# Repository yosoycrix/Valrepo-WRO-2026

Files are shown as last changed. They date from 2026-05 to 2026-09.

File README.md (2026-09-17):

# Equipo [Team ValGrind]: WRO 2026

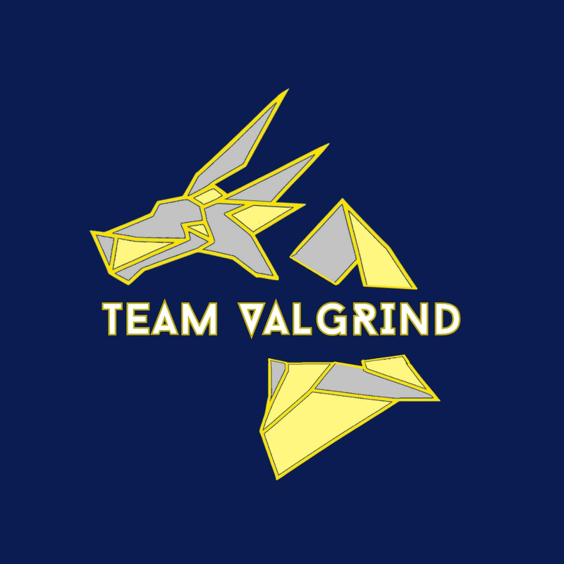
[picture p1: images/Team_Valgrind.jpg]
Team Photo


---

# Índice

- [1. Nuestro Equipo](#1-nuestro-equipo)
  - [1.1 Integrantes](#11-integrantes)
  - [1.2 Origenes](#12-origenes)
  - [1.3 Nuestro Objetivo](#13-nuestro-objetivo)
- [2. El Robot](#2-el-robot)
  - [2.1 Videos del Robot](#21-videos-del-robot)
  - [2.2 Apartado Mecanico](#22-apartado-mecanico)
  - [2.3 Impresion 3D](#23-Impresion-3d)
    - [2.3.1 Justificacion de Diseño](#231-justificación-de-diseño)
  - [2.4 Movilidad](#24-movilidad)
  - [2.5 Sistema de Movimiento y Traccion](#25-sistema-de-movimiento-y-traccion)
  - [2.6 Piezas de Mecanica](#26-piezas-de-mecanica)
    - [2.6.1 Diferencial y Eje de transmision](#261-diferencial-y-eje-de-transmisión-impreso-en-3d)
    - [2.6.2 Servomotor](#262-servomotor-injora-180)
    - [2.6.3 Motor](#263-motor-hytech-ga37-520)
    - [2.6.4 Tornillos, Tuercas y Arandelas](#264-tornillos-tuercas-de-seguridad-y-arandelas-m2-y-m3)
- [3. Apartado Electronico](#3-apartado-electronico)
  - [3.1 Piezas de Electronica](#31-piezas-de-electronica)
    - [3.1.1 Baterias](#311-baterias)
    - [3.1.2 Step Down](#312-step-down)
    - [3.1.3 Motor Driver](#313-motor-driver)
    - [3.1.4 Ultrasonico](#314-sensor-de-ultrasonido)
    - [3.1.5 Giroscopio](#315-giroscopio)
    - [3.1.6 Huskylens](#316-huskylens-2)
  - [3.2 Microcontrolador](#32-microcontrolador)
    - [3.2.2 ESP32](#322-esp32-wroom-32)
  - [3.3 Diagrama de Conexiones](#33-diagrama-de-conexiones)
    - [3.3.1 Distribucion de Pines](#331-distribucion-de-pines)
    - [3.3.2 Estrategia de Corriente](#332-estrategia-de-corriente)
    - [3.3.3 Sistema de Alimetacion](#333-sistema-de-alimentacion)
- [4. Apartado de Programacion](#4-apartado-de-programacion)
  - [4.1 Desafio Abierto](#41-desafio-abierto)
    - [4.1.1 Flowchart Abierta](#411-flowchart-abierta)
    - [4.1.2 Explicación del Codigo](#412-explicacion-del-codigo)
    - [4.1.3 Pruebas en Pista](#413-pruebas-en-pista)
  - [4.2 Desafio Cerrado](#42-desafio-cerrado)
    - [4.2.1 Flowchart Cerrada](#421-flowchart-cerrada)
    - [4.2.2 Explicación del Codigo](#422-explicacion-del-codigo)
    - [4.2.3 Pruebas de Esquivamiento](#423-pruebas-de-esquivamiento)
- [5. Pensamiento Sistemico y Decisiones de Ingeneria](#5-pensamiento-sistemico-y-decisiones-de-ingeneria)
  - [5.1 Enfoque de Pensamiento Sistemico](#51-enfoque-de-pensamiento-sistémico)
  - [5.2 Trade Offs e Iteraciones de Ingeneria](#52-trade-offs-e-iteraciones-de-ingeniería)
  - [5.3 Validacion Robutez e Itegracion Tecnica](#53-validación-robustez-e-integración-técnica)
  - [5.4 Diario de Ingeneria Bitacora de Componentes e Iteraciones](#54-diario-de-ingeniería-bitácora-de-componentes-e-iteraciones)
- [6. Randomizador](#6-Randomizador)
- [7. Recursos para armar nuestro robot](#7-recursos-para-hacer-el-robot)

---

## Estructura del Repositorio
- [T-photos/](https://github.com/yosoycrix/Valrepo-WRO-2026/tree/main/t-photos) - Fotos del Team
- [V-photos/](https://github.com/yosoycrix/Valrepo-WRO-2026/tree/main/v-photos) - Fotos del Robot
- [Schemes/](https://github.com/yosoycrix/Valrepo-WRO-2026/tree/main/schemes) - Eschematic diagrams
- [Src/](https://github.com/yosoycrix/Valrepo-WRO-2026/tree/main/src) - Codigo
- [Models/](https://github.com/yosoycrix/Valrepo-WRO-2026/tree/main/models) - Diseños 3D
- [Others/](https://github.com/yosoycrix/Valrepo-WRO-2026/tree/main/others) - Otros archivos
- [Videos/](https://github.com/yosoycrix/Valrepo-WRO-2026/tree/main/videos) - Videos
- [Images/](https://github.com/yosoycrix/Valrepo-WRO-2026/tree/main/images) - Imagenes
      
---

## 1. Nuestro Equipo

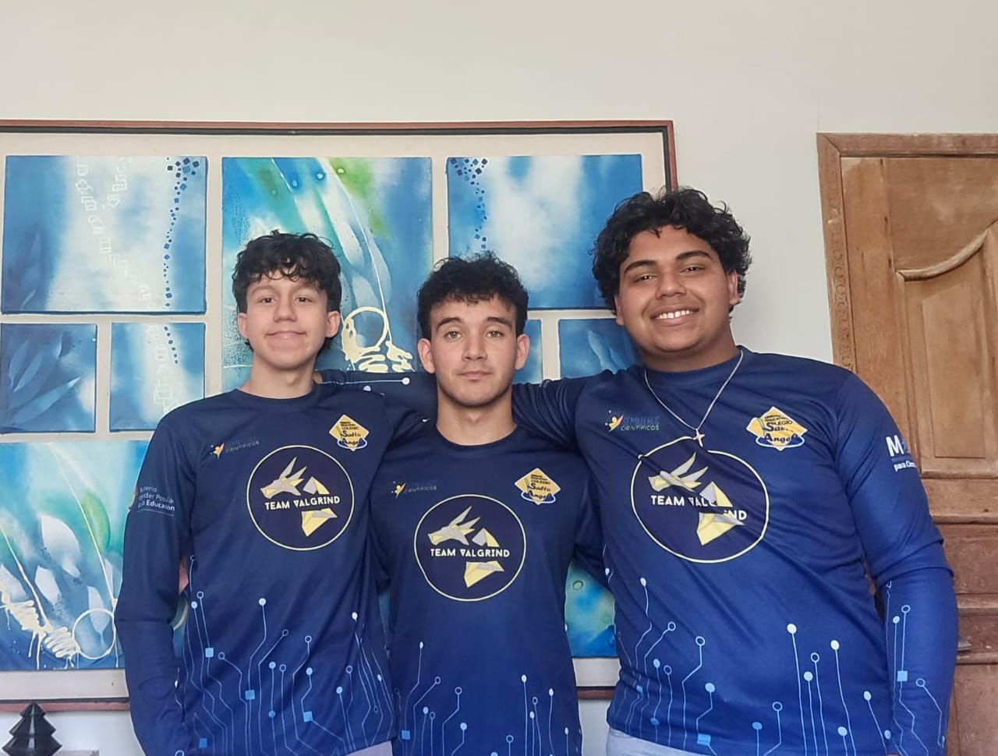
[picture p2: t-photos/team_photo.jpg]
Team Photo


Somos **[Team ValGrind]**, entusiastas de la robótica y la innovación. Representamos a nuestra institución en las fases Regionales de la **WRO 2026**.

---

### 1.1 Integrantes

<table>
  <tr>
    <!-- Foto de Perfil -->
    <td width="280px" align="center" style="border: none;">
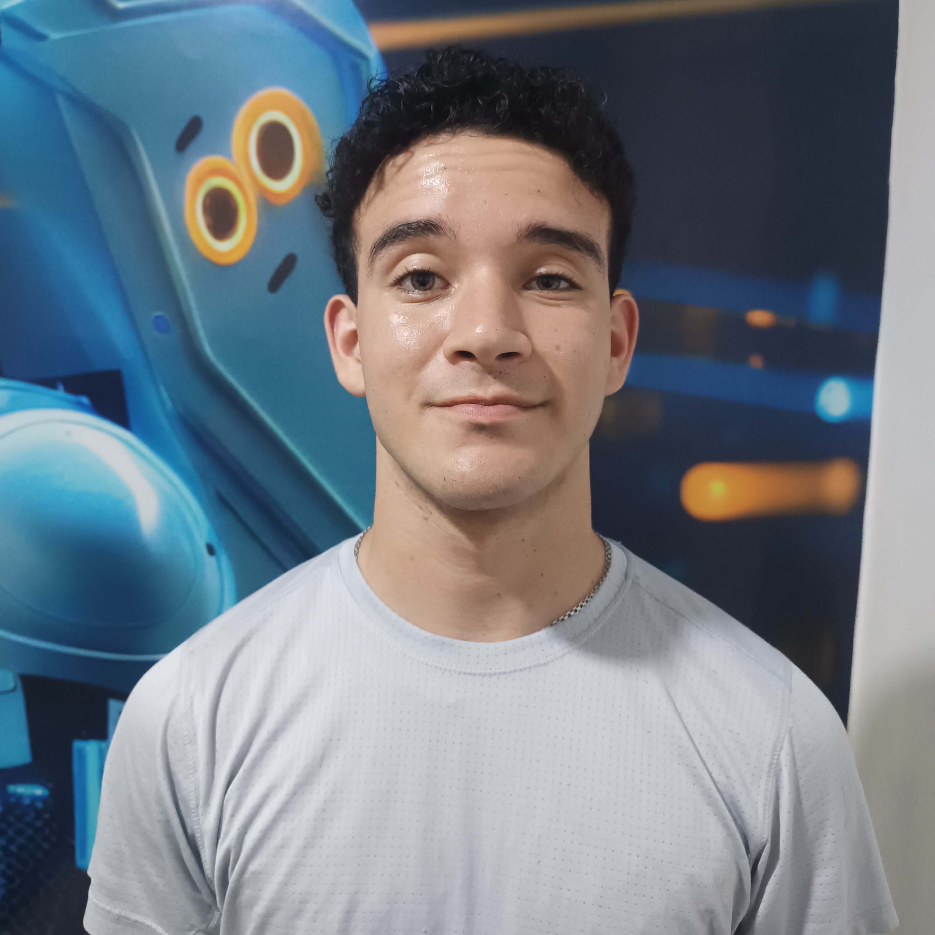
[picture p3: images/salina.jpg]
      
    </td>
    <!-- Información del Integrante -->
    <td style="border: none; padding-left: 20px; vertical-align: top;">
      <h2>Sebastián Salina</h2>
      <p><b>🎂 Edad:</b> 18 años (22/08/2008)</p>
      <p><b>🎖️ Rol:</b> Capitán / Mecánico del equipo</p>
      <hr>
      <p><b>🛠️ Habilidades:</b></p>
      <ul>
        <li>Estudiante de ing Mecatronica.</li>
        <li>Diseño de piezas en 3D (CAD).</li>
        <li>Tecnico en impresión 3D.</li>
        <li>Mantenimiento y ensamblaje mecánico.</li>
      </ul>
      <p><b>✨ Fun Fact:</b> <i>Una vez imprimió un Pokémon gigante de filamento para Cristóbal.</i></p>
    </td>
  </tr>
</table>

<table>
  <tr>
    <!-- Foto de Perfil -->
    <td width="280px" align="center" style="border: none;">
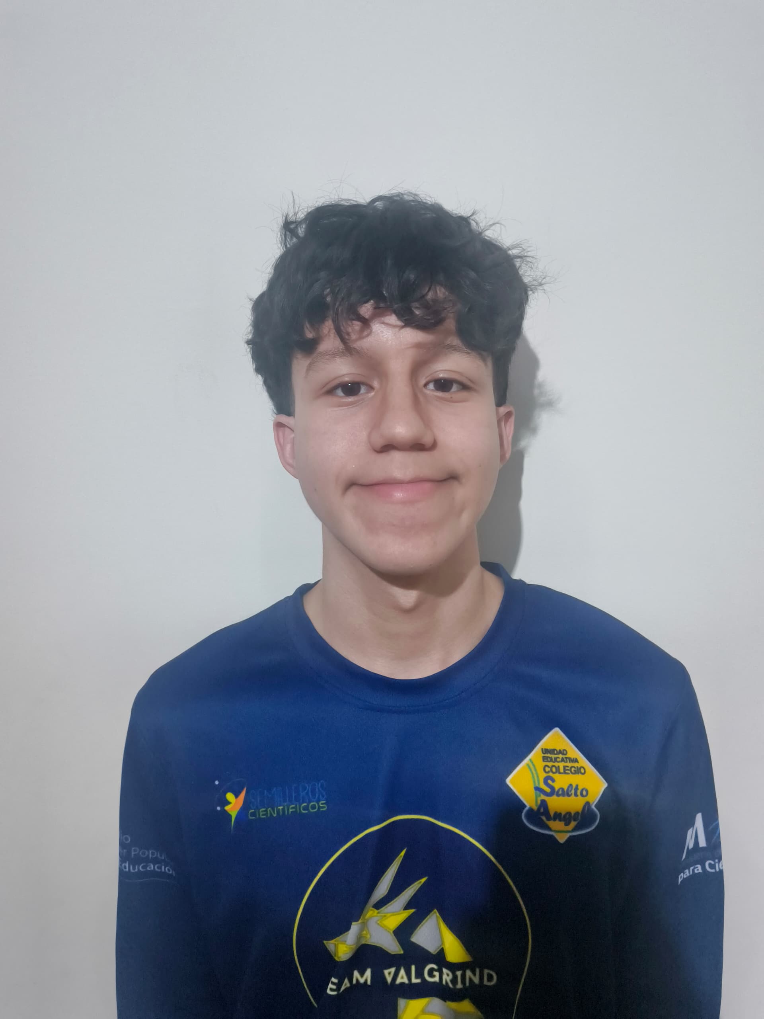
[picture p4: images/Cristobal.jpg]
      
    </td>
    <!-- Información del Integrante -->
    <td style="border: none; padding-left: 20px; vertical-align: top;">
      <h2>Cristobal Mogollón</h2>
      <p><b>🎂 Edad:</b> 16 años (14/07/2010)</p>
      <p><b>🎖️ Rol:</b> Programador / Documentador</p>
      <hr>
      <p><b>💻 Habilidades:</b></p>
      <ul>
        <li>Programación en C++ y Arduino IDE.</li>
        <li>Manejo de la electrónica y sensores.</li>
        <li>Dominio con Git y GitHub.</li>
      </ul>
      <p><b>✨ Fun Fact:</b> <i>Una vez le pidió a Sebastián imprimir un Pokémon gigante de filamento.</i></p>
    </td>
  </tr>
</table>

<table>
  <tr>
    <!-- Foto de Perfil -->
    <td width="280px" align="center" style="border: none;">
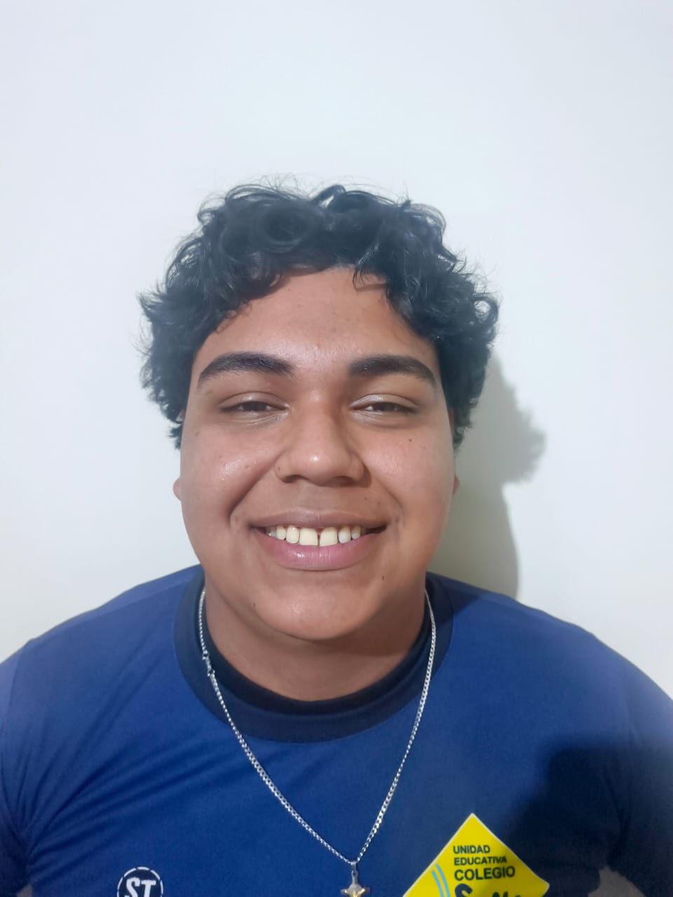
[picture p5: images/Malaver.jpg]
      
    </td>
    <!-- Información del Integrante -->
    <td style="border: none; padding-left: 20px; vertical-align: top;">
      <h2>Diego Malaver</h2>
      <p><b>🎂 Edad:</b> 16 años (09/09/2010)</p>
      <p><b>🎖️ Rol:</b> Mecanico / Electronico</p>
      <hr>
      <p><b>⚙️ Habilidades:</b></p>
      <ul>
        <li>Manejo de la Mecanica.</li>
        <li>Manejo de la electrónica.</li>
        <li>Dominio con Github.</li>
      </ul>
      <p><b>✨ Fun Fact:</b> <i>Le prestaron la camisa de Cristobal del equipo y le quedo apretada.</i></p>
    </td>
  </tr>
</table>

- **Institución:** [Colegio Salto Ángel](https://www.instagram.com/colegiosaltoangel)
- **Instagram Oficial:** [@team_valgrind](https://instagram.com/team_valgrind)
- **Contáctanos:** [valgrind2026@gmail.com](mailto:valgrind2026@gmail.com)
- **Youtube:**
[Team ValGrind](https://youtube.com/@teamvalgrind?si=ZJbz7CX9eOX75H2U)

---

### 1.2 Origenes

El nombre de nuestro equipo fue decidido por los tres integrantes a partir de un clásico compilador de C++ llamado de la misma forma, el cual es representado por un logotipo de un dragón hecho con origami. El nombre "ValGrind" también hace referencia a la mitología nórdica debido a las legendarias Valquirias que habitan en este.

 (https://postimg.cc/gryddns4)

> ### ¿Por qué nuestro robot se llama Heimdall?

Este nombre no solo es un guiño a la mitología mencionada, sino que además corresponde al dios conocido como el guardián de las puertas de Asgard y del puente Bifröst, que conecta los Nueve Mundos. Al ser un personaje imponente, consideramos que es un nombre apropiado para representar a nuestro robot en la WRO.

---  

### 1.3 Nuestro Objetivo

(https://postimg.cc/t1LyR68v)

#### "Diseñar, Construir y Programar"
 Un robot autónomo capaz de superar los desafíos de la WRO 2026, utilizando innovación y trabajo en equipo para lograr un desempeño sobresaliente en la etapa regional y avanzar a la nacional. Para llegar a esto, hemos pasado los últimos meses diseñando, construyendo, armando y programando nuestro más nuevo proyecto "Heimdall"

> [!NOTE]
> La World Robot Olympiad (WRO) es una competencia internacional de robótica educativa que se desarrolla en varias fases, y nuestro equipo lógicamente tiene que comenzar por la fase regional, mediante la cual al ganarla se accede a la Fase Nacional. Cada país organiza su propio torneo clasificatorio, donde equipos de jóvenes compiten en distintas categorías, aplicando conocimientos de robótica y STEAM. Por último, la fase a la cual nuestro equipo quiere llegar es la Final Internacional. Los equipos ganadores de cada país participan en la competencia global, donde enfrentan desafíos más complejos y compiten con representantes de más de 95 países 

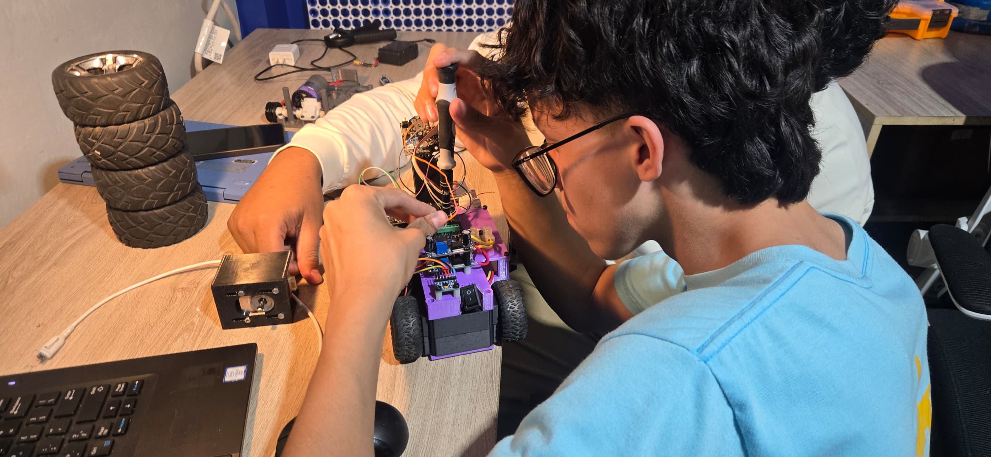
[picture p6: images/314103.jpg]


Aún así, nuestro único objetivo no es solamente ganar, como un equipo unido también tenemos la convicción de poder crear un robot no solo funcional, sino que llene nuestras expectativas; A pesar de ser intangible nuestro deseo de poder culminar nuestro proyecto como un equipo unido y verlo brillar, también es una meta importante para nosotros.

<p align="right">
  <a href="#inicio">Volver Al Inicio</a>
</p>

---

## 2. El Robot

<table>
  <tr>
    <td align="center">
      <b>Frontal</b><br>
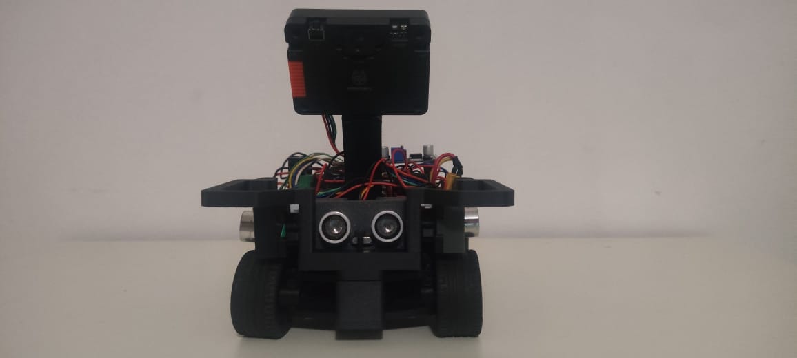
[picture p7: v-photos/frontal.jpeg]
      
    </td>
    <td align="center">
      <b>Posterior</b><br>
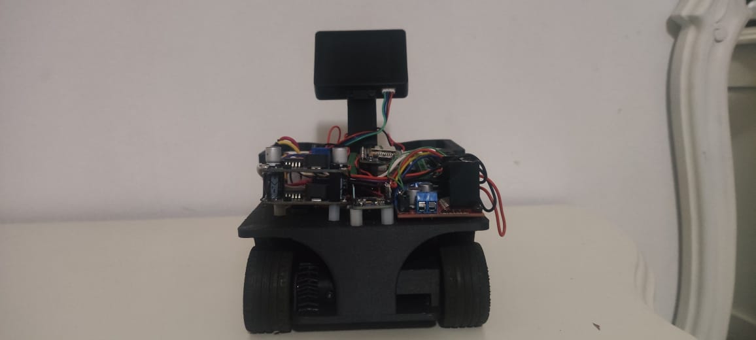
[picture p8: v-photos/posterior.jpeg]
      
    </td>
    <td align="center">
      <b>Lado Izquierdo</b><br>
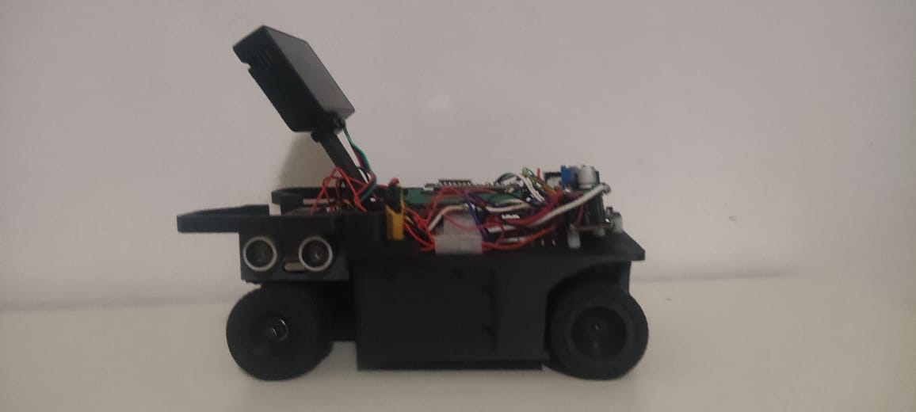
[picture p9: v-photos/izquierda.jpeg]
      
    </td>
  </tr>
  <tr>
    <td align="center">
      <b>Lado Derecho</b><br>
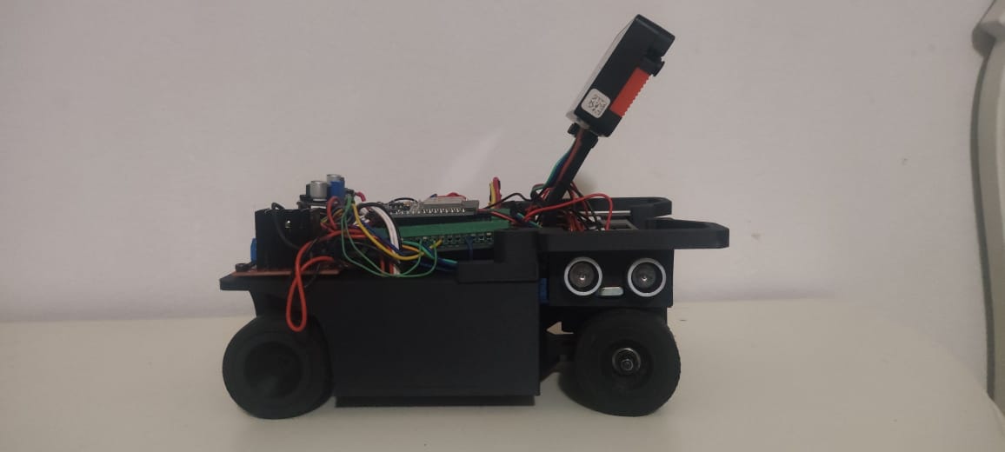
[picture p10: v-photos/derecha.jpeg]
      
    </td>
  <td align="center">
  <b>Superior</b><br>
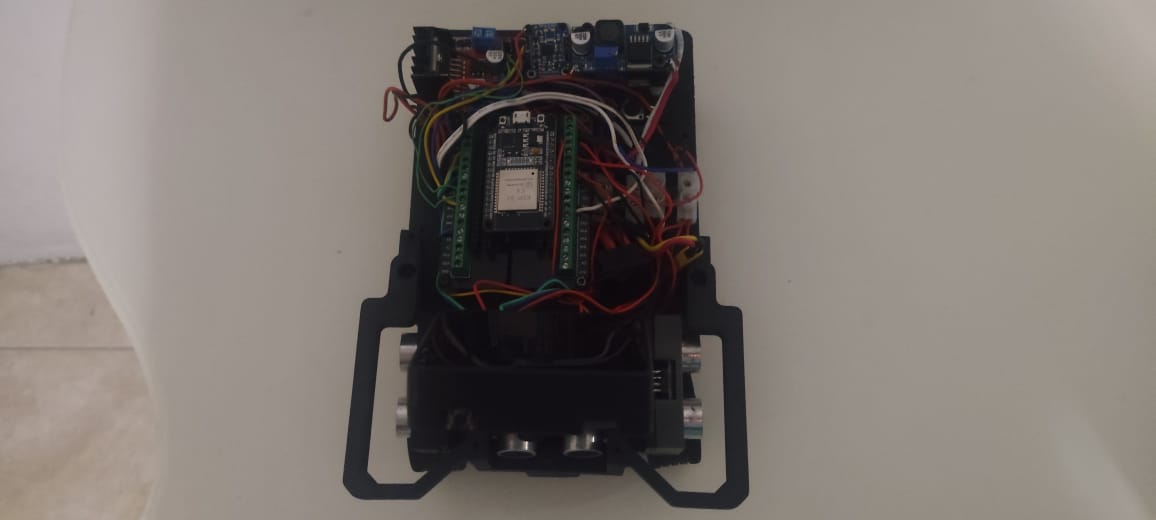
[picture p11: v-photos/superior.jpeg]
  
</td>
    <td align="center">
      <b>Inferior</b><br>
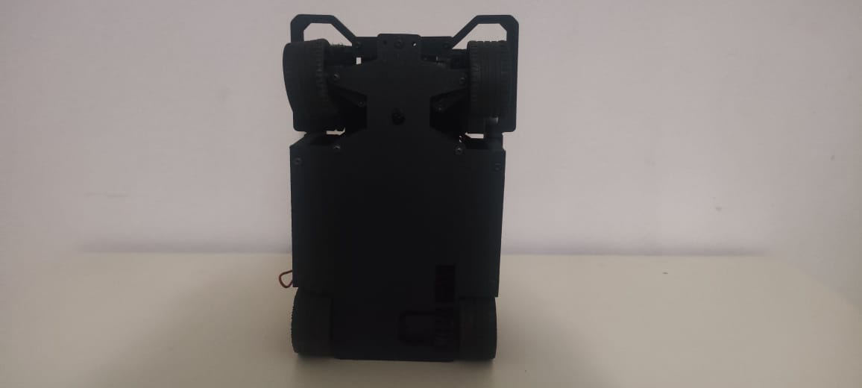
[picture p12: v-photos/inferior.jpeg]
      
    </td>
  </tr>
</table>

---

## 2.1 Videos Del Robot

<h3 align="left" style="font-size: 1.4em; font-weight: 800; color: #1f2328; margin-bottom: 12px; text-transform: uppercase; letter-spacing: 0.5px;"><strong>Open Challenge</strong></h3>

<section style="display: block; width: 100%;">
  <table align="left" style="border-collapse: collapse; border: none; margin-top: 0px; width: 100%;">
    <tr style="border: none;">
      <td align="center" style="padding: 10px; border: none; width: 50%; vertical-align: top;">
        <a href="https://www.youtube.com/watch?v=DzKUt2QOpJs" target="_blank" style="text-decoration: none; display: inline-block;">
          Open Challenge Video 3
          <br />
          <span style="color: #0366d6; font-size: 0.9em; font-weight: 500; display: inline-block; margin-top: 8px;">▶ Video Open Challenge #3</span>
        </a>
      </td>
      <td align="center" style="padding: 10px; border: none; width: 50%; vertical-align: top;">
        <a href="https://www.youtube.com/watch?v=JyEaFMhT2mY" target="_blank" style="text-decoration: none; display: inline-block;">
          Open Challenge Video 4
          <br />
          <span style="color: #0366d6; font-size: 0.9em; font-weight: 500; display: inline-block; margin-top: 8px;">▶ Video Open Challenge #4</span>
        </a>
      </td>
    </tr>
  </table>
</section>

<br clear="all" />

<h3 align="left" style="font-size: 1.4em; font-weight: 800; color: #1f2328; margin-bottom: 12px; text-transform: uppercase; letter-spacing: 0.5px;"><strong>Obstacle Challenge</strong></h3>

<section style="display: block; width: 100%;">
  <table align="left" style="border-collapse: collapse; border: none; margin-top: 0px; width: 50%;">
    <tr style="border: none;">
      <td align="center" style="padding: 10px; border: none; width: 100%; vertical-align: top;">
        <a href="https://www.youtube.com/watch?v=xPg1Bdj31Bs" target="_blank" style="text-decoration: none; display: inline-block;">
          Obstacle Challenge Video 1
          <br />
          <span style="color: #0366d6; font-size: 0.9em; font-weight: 500; display: inline-block; margin-top: 8px;">▶ Video Obstacle Challenge #1</span>
        </a>
      </td>
    </tr>
  </table>
</section>

<br clear="all" />

---

## 2.2 Apartado Mecanico

### 2.3 Impresion 3D

Antes de hablar de la movilidad o funcionalidad de nuestro robot, primero hay que explicar nuestros métodos de Diseño e Impresión 3D, los cuales se llevaron a cabo mediante Fusion 360

> [!NOTE]
> Fusion 360 es una plataforma de software de modelado 3D, CAD, CAM, CAE y PCB basada en la nube, destinada al diseño y la fabricación de productos. Nos permite diseñar y crear productos de acuerdo a sus especificaciones particulares, garantizando que cada pieza cumpla con los más exigentes criterios de estética, forma, ajuste y funcionalidad. Además, incorpora un conjunto integral de herramientas avanzadas para el diseño de placas de circuito impreso y componentes electrónicos, lo que facilita la conceptualización y materialización de cualquier idea, incluso las más complejas. Al implementar estas funciones, la plataforma optimiza significativamente tanto el tiempo como los costos asociados, asegurando que el proceso de producción se realice de manera eficiente y que las piezas obtenidas sean de la más alta calidad. Nosotros usamos esta herramienta gráfica y de diseño para realizar los diseños del chasis y las piezas personalizadas de nuestro robot.

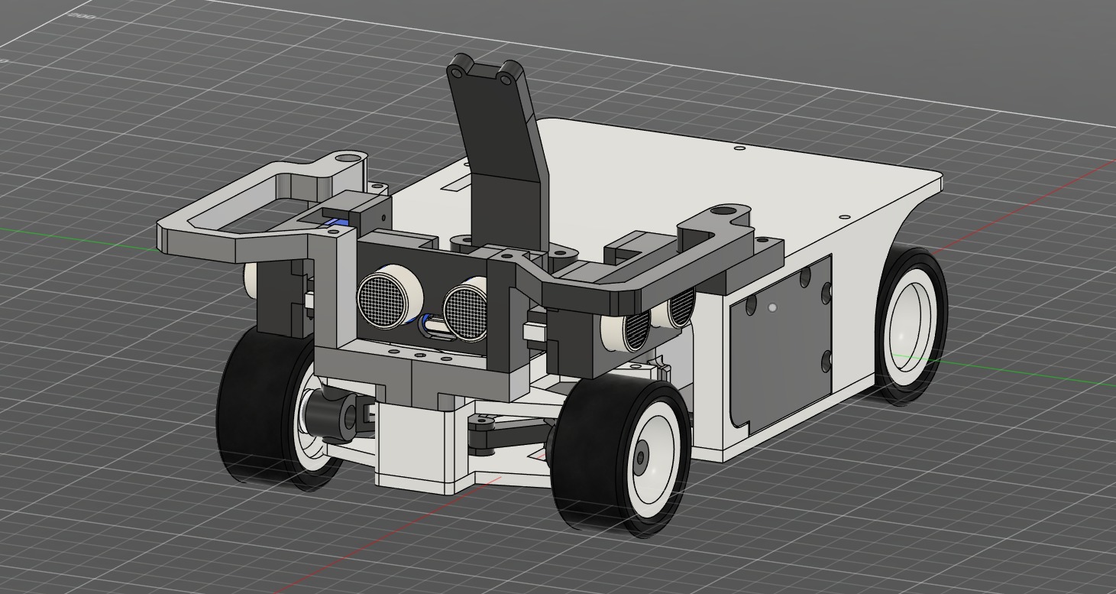
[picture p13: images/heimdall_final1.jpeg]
Hei=mdall3d


## 2.3.1 Justificación de Diseño

El desarrollo mecatrónico del prototipo se concibió bajo la filosofía de diseño **"compacto, funcional y robusto"**, buscando maximizar la eficiencia en pista, optimizar el uso del espacio interno y garantizar una respuesta dinámica precisa sin comprometer la rigidez estructural.

---

### Dimensionamiento y Distribución Espacial

El robot cuenta con una estructura de dimensiones reducidas de **19.6 cm de largo por 12.5 cm de ancho**, posicionándose como un chasis ultra compacto. Esta decisión de diseño persigue objetivos clave:
* **Centro de gravedad bajo y balanceado:** La disposición horizontal de los componentes internos distribuye la masa en un solo plano horizontal, minimizando la inercia rotacional y evitando volcamientos en maniobras a alta velocidad.
* **Maniobrabilidad en pista:** El empaquetamiento compacto permite abordar curvas cerradas con mayor radio de giro efectivo dentro del trazado.
* **Rigidez estructural:** La densidad del chasis y la calidad de construcción eliminan la flexión ante aceleraciones bruscas y cambios repentinos de dirección.

---

### Tren Delantero y Dirección Ackermann

A diferencia de los sistemas de dirección convencionales con múltiples eslabones flotantes, se implementó una variante de **geometría Ackermann positivo** conectada directamente a un servomotor central.

<p align="center">
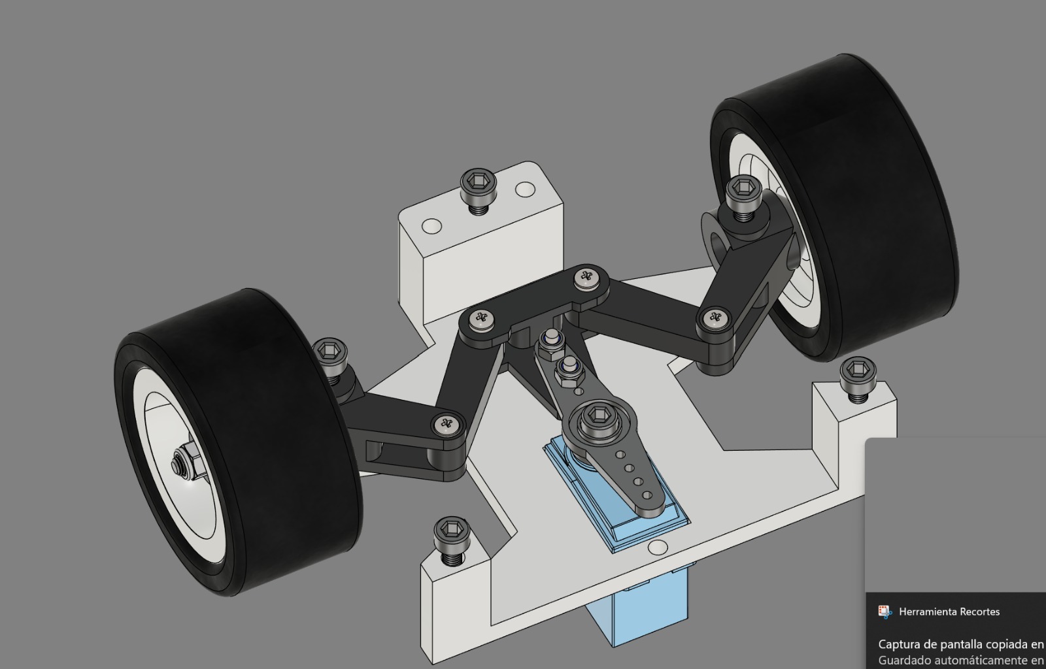
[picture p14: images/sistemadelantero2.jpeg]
Sistema de Dirección y Tren Delantero
  
</p>

* **Respuesta Inmediata y Cero Holguras:** Al acoplar el brazo del servomotor directamente al mecanismo de articulación de la dirección, se eliminan los puntos de juego mecánico. Esto garantiza un control de trayectoria inmediato y repetible.
* **Geometría Estable en un Solo Plano:** El mecanismo mantiene una geometría matemática pura que previene la alteración de los ángulos de giro ante fuerzas laterales generadas por el agarre en curvas.
* **Optimización de Torque y Energía:** Dado que el mecanismo ofrece una ventaja mecánica optimizada, el servomotor realiza un recorrido menor para lograr un ángulo de cruce agresivo, reduciendo la fricción, el desgaste mecánico y el consumo eléctrico pico.

---

### Rodadura y Acoplamiento a Medida

Para transmitir el torque al suelo de manera eficiente y mantener una baja distancia sensorial, se diseñó un sistema de rodadura a medida impreso en 3D.

<p align="center">
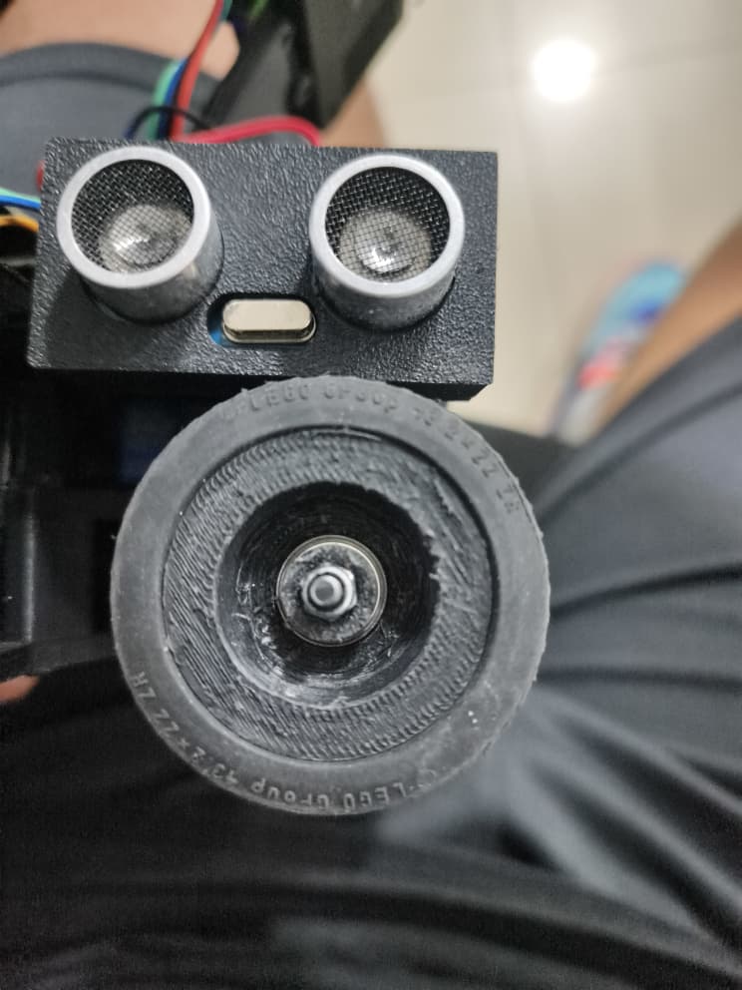
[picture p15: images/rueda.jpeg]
Detalle de Rueda y Rin Impreso en 3D
  
</p>

* **Rines Impresos en 3D con Alojamiento para Doble Rodamiento:** Los rines se diseñaron a medida con unas dimensiones de **43 mm de diámetro exterior por 22 mm de ancho**. Cada rin cuenta con una ranura interna a cada lado diseñada para alojar **dos rodamientos de bolas**, lo que elimina por completo el cabeceo de la rueda sobre el manguito/nudillo de dirección y garantiza una libertad de rotación fluida.
* **Tracción y Distancia Sensorial:** La geometría del conjunto rueda/rin asegura una superficie de contacto uniforme contra el vinil de la pista. Además, al mantener un perfil compacto de 43 mm, el chasis permanece lo suficientemente bajo como para ubicar los sensores ultrasónicos y la matriz de navegación a una distancia óptima del suelo.

---

### Transmisión y Diferencial Helicoidal Modificado

La etapa de tracción trasera resuelve uno de los principales retos de empaquetamiento mecánico mediante el rediseño integral de una caja diferencial compacta.

<p align="center">
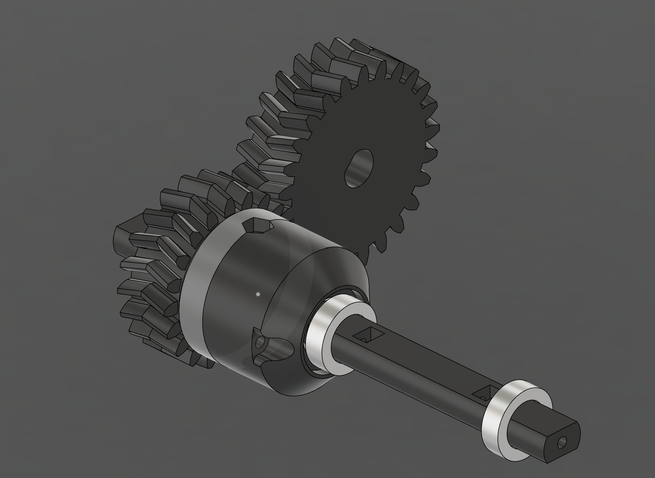
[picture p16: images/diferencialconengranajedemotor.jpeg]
Diseño CAD del Diferencial y Piñón Helicoidal
  
</p>

<p align="center">
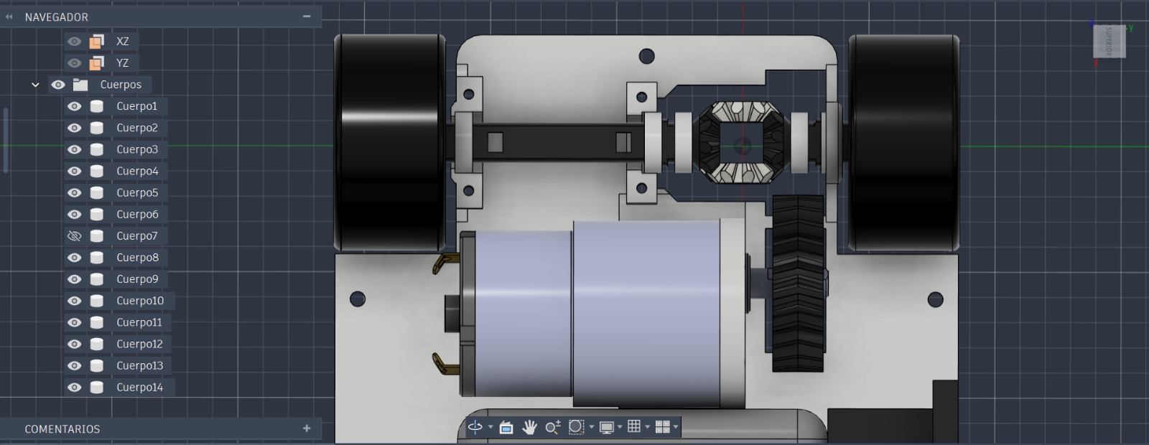
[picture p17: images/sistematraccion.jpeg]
Corte y Ensamblaje del Sistema de Tracción Trasera
  
</p>

* **Engranajes Helicoidales Dobles (Spur / Herringbone):** La corona externa del diferencial y el piñón de ataque del motor fueron rediseñados como engranajes helicoidales dobles. Este perfil cancela las fuerzas axiales y permite posicionar el motor de tracción de forma totalmente **horizontal y paralela al eje trasero**.
* **Reducción de Longitud (2 cm de ahorro):** La disposición horizontal del motor redujo la longitud total del chasis en **2 cm**, liberando el espacio central requerido para alojar la batería y el servo de dirección.
* **Cinemática Interna Eficiente:** Internamente, el diferencial conserva su configuración estándar de engranajes cónicos planetarios y satélites, asegurando una correcta distribución de torque entre las ruedas izquierdas y derechas al abordar curvas sin perder tracción ni forzar los motores.

---

### Integración Mecatrónica y Ensamblaje Final

El ensamblaje integral consolidado demuestra la convergencia de todos los subsistemas en una sola arquitectura monocasco y modular.

<p align="center">
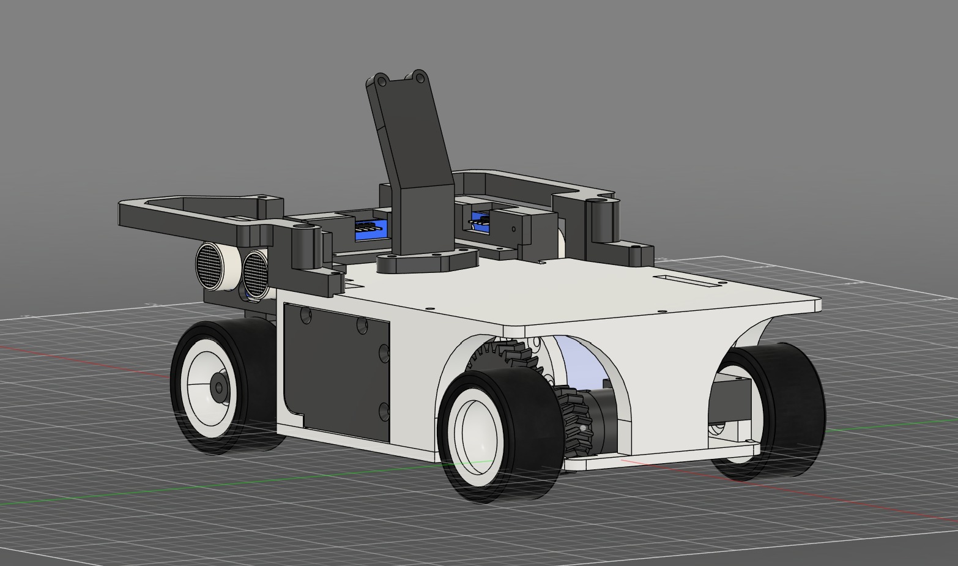
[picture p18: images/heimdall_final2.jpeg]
Vista Isométrica Trasera del Chasis Ensamblado
  
</p>

<p align="center">
  Vista Isométrica Frontal con Sensores Integrados
</p>

* **Optimizaciones de Espacio Integradas:** Se evidencia la integración total del chasis compacto de **19.6 cm x 12.5 cm**, donde la bahía central alojada sobre la tracción trasera aprovecha exactamente los **2 cm de ahorro** logrados por la caja de transmisión helicoidal.
* **Soportes Estructurales para Sensórica:** La torre central y la bahía frontal están moldeadas específicamente para soportar los módulos de visión y los sensores ultrasónicos de distancia sin sobredimensionar la huella (*footprint*) del vehículo ni interferir con el radio de giro de la dirección Ackermann.

---

## 2.4 Movilidad

### Justificación Técnica de la Arquitectura de Movilidad de *Heimdall*

Una vez definidas la selección, diseño y manufactura por impresión 3D de los componentes mecánicos de *Heimdall*, el siguiente hito fundamental consiste en garantizar un sistema de locomoción que combine alta maniobrabilidad, velocidad y control preciso para enfrentar las exigencias del circuito de competencia.

Para responder a estos requerimientos, se desestimaron las configuraciones tradicionales de robótica móvil orientándonos hacia una arquitectura inspirada en la automoción de alto rendimiento: **Dirección delantera con Geometría Ackermann Positiva asistida por Servo, acoplada a una Tracción Trasera Diferencial con Encoders**.

```mermaid
graph TD
    A["Análisis de Requerimientos en Pista"] --> B["Búsqueda de Máxima Adherencia y Altas Velocidades"]
    B --> C["Selección: Dirección Ackermann Positiva + Tracción Trasera"]
    
    C --> D["Eje Delantero: Dirección Guiada"]
    C --> E["Eje Trasero: Tracción y Empuje"]
    
    D --> F["Geometría Ackermann (CIR Único)"]
    E --> G["Diferencial / Encoders Independientes"]
    
    F --> H["Rodadura Limpia (0% Arrastre Transversal)"]
    G --> I["Potencia Constante sin Pérdida de Control"]
```
#### ¿Por qué elegimos esta arquitectura sobre otros sistemas?

**1. Dinámica de Giro y Geometría del Centro Instantáneo de Rotación (CIR):**
En un vehículo en viraje, la rueda ubicada en el interior de la curva describe un arco con un radio notablemente menor que la rueda ubicada en el exterior. Si ambas ruedas girasen en el mismo ángulo (dirección paralela), la rueda interna se vería forzada a arrastrarse transversalmente sobre el piso. 

La **Geometría Ackermann Positiva** resuelve este dilema mediante un eslabonamiento mecánico diseñado para que el ángulo de viraje de la rueda interna ($\theta_{in}$) sea mayor que el de la rueda externa ($\theta_{out}$). Esto garantiza que las perpendiculares trazadas desde los ejes de ambas ruedas delanteras y el eje trasero converjan en un único punto geométrico conocido como el **Centro Instantáneo de Rotación (CIR)**.

```mermaid
graph LR
    subgraph Geometria_Ackermann[" Principio del CIR Único "]
        direction TB
        R1["Rueda Delantera Interior (Ángulo Mayor θ_in)"]
        R2["Rueda Delantera Exterior (Ángulo Menor θ_out)"]
        R3["Eje Trasero Rígido / Diferencial"]
    end
    
    R1 -->|"Perpendicular"| CIR(("Punto CIR Único"))
    R2 -->|"Perpendicular"| CIR
    R3 -->|"Prolongación del Eje"| CIR
```

<p align="center">
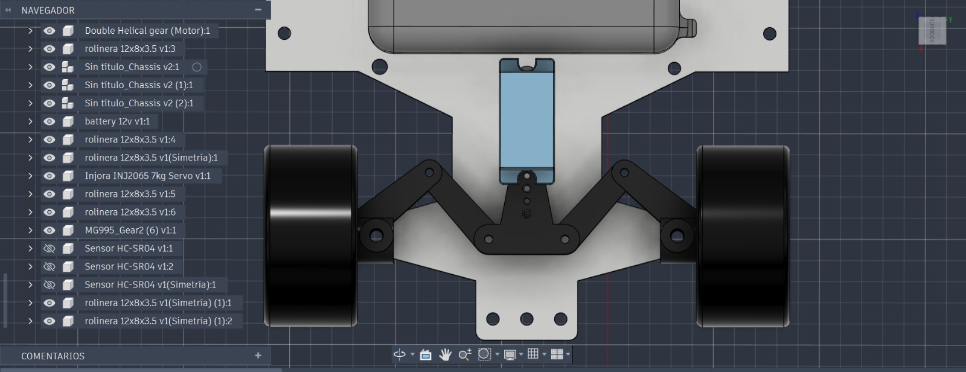
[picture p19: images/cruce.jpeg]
Delantera del vehículo
  
  <br>
  <em>Figura 2.1: Implementación del tren delantero de Heimdall con manguetas y servo de dirección Ackermann.</em>
</p>

> [!NOTE]
> **Función del Diferencial en el Eje de Tracción:**
> El diferencial permite que exista una diferencia en la velocidad de giro entre la rueda interna y la rueda externa del vehículo al tomar una curva. Independientemente de si la tracción es delantera o trasera, este mecanismo es vital para evitar el deslizamiento de las ruedas motrices cuando recorren distancias desiguales durante un viraje.

<p align="center">
  <a href="https://postimg.cc/G4sWpg3Z" target="_blank">
    Diagrama Mecánico del Diferencial
  </a>
  <br>
  <em>Figura 2.2: Esquema cinemático del diferencial trasero implementado en el sistema de tracción.</em>
</p>

**2. Optimización del Agarre y Conservación de Energía:**
En la tracción diferencial pura (2WD o tipo tanque), los giros se efectúan forzando el deslizamiento relativo de los cauchos contra la pista. En *Heimdall*, al lograr una rodadura pura mediante Ackermann, se elimina el desprendimiento de fricción parásita. Esto trae tres grandes ventajas mecánicas y térmicas:
* **Cero Arrastre Lateral:** Previene el desgaste acelerado y el ablandamiento de los cauchos por fricción térmica.
* **Reducción de Esfuerzos Estructurales:** Evita someter los nudillos, manguetas y chasis impresos en **PETG-CF** a momentos de torsión o esfuerzo cortante innecesarios.
* **Eficiencia Energética:** La Batería LiPo no pierde energía disipando potencia contra la pista en forma de fricción, maximizando la aceleración disponible en tramos rectos.

**3. Transición de Carga y Estabilidad de Lectura (IMU y Odometría):**
Los cambios bruscos de orientación típicos de la tracción diferencial generan sobrepicos en el giroscopio y desacoplamientos bruscos en el PID de dirección. El viraje guiado por Ackermann genera una transferencia de peso progresiva hacia las ruedas exteriores durante la curva. Esto garantiza lecturas estables en el giroscopio **BNO055** y evita descalibraciones en los *encoders* traseros, permitiendo una odometría de altísima fidelidad.

---

#### Desglose de Inconvenientes de las Alternativas Rechazadas

* **Tracción Diferencial Pura (2WD / Tank Drive):** Aunque es mecánicamente simple, su dinámica a alta velocidad provoca el efecto conocido como *chattering* o bamboleo del PID cuando intenta corregir trayectoria en recta. Además, no cuenta con un eje de dirección independiente, forzando al algoritmo a alternar constantemente la potencia de los motores.
* **Sistemas Holonómicos (Omnidireccionales / Mecanum):** A pesar de su capacidad para desplazarse en 360°, los rodillos de las ruedas omnidireccionales sufren de un margen de deslizamiento constante (*slip ratio*). Esto hace impredecible la trayectoria matemática a alta velocidad y destruye la odometría por fricción irregular contra el suelo.

---

### Cuadro Comparativo de Opciones de Sistema de Transmision/Direccion 

| Criterio de Selección | Dirección Ackermann + Tracción Trasera (*Heimdall*) | Tracción Diferencial Pura (2WD / Tanque) | Sistemas Holonómicos (Omni / Mecanum) |
| :--- | :--- | :--- | :--- |
| **Mecanismo Cinemático** | Servo en eje delantero con trapecio Ackermann + Motores en eje trasero | Diferencia de velocidad angular entre ruedas izquierda y derecha | Vectores de velocidad independientes en 3 o 4 ruedas con rodillos |
| **Punto CIR (Centro Instantáneo)** | **Único y Variable:** Convergencia geométrica perfecta en todo el rango de giro | **Fijo en el Eje Trasero:** Fuerza el arrastre del resto de la estructura | **Inexistente / Volátil:** Cambia según el deslizamiento de los rodillos |
| **Estabilidad a Alta Velocidad** | **Muy Alta:** Comportamiento idéntico al de un vehículo real sin coleos | **Media/Baja:** Propenso a sobrevirajes e inestabilidad del PID de dirección | **Baja:** El movimiento vectorial es susceptible a turbulencias y derrapes |
| **Eficiencia de Fricción** | **Máxima:** Rodadura pura sin arrastre transversal de los cauchos | **Baja:** Las ruedas sufren arrastre transversal continuo durante giros | **Muy Baja:** Pérdida masiva de potencia por el juego libre de los rodillos |
| **Fiabilidad de Odometría (Encoders + IMU)** | **Muy Alta:** El deslizamiento mínimo garantiza lecturas lineales exactas | **Media:** El derrape en curvas introduce errores acumulativos en la posición | **Deficiente:** El vector de desplazamiento sufre deslizamiento imponderable |
| **Radio Mínimo de Giro** | Limitado mecánicamente por el rango del servo y geometría de manguetas | Giro sobre su propio centro de masa (Radio cero) | Omnidireccional (Capacidad de desplazamiento lateral directo) |
| **Complejidad de Control** | **Optimizada:** Control desacoplado (Servo = Dirección, Motores = Tracción) | **Acoplada:** Tracción y Dirección comparten los mismos actuadores | **Compleja:** Exige matrices de transformación cinemática continuas |

### 2.5 Sistema de Movimiento y Tracción

<p>Ahondando en lo mencionado anteriormente, <em>Heimdall</em> utiliza un <strong>sistema Ackermann positivo</strong>, cuyo objetivo es lograr que en curvas la <strong>rueda interior (&theta;<sub>i</sub>) gire más que la exterior (&theta;<sub>o</sub>)</strong> para minimizar el deslizamiento lateral (<em>scrub</em>) y garantizar un trazo limpio a alta velocidad.</p>

<p align="center">
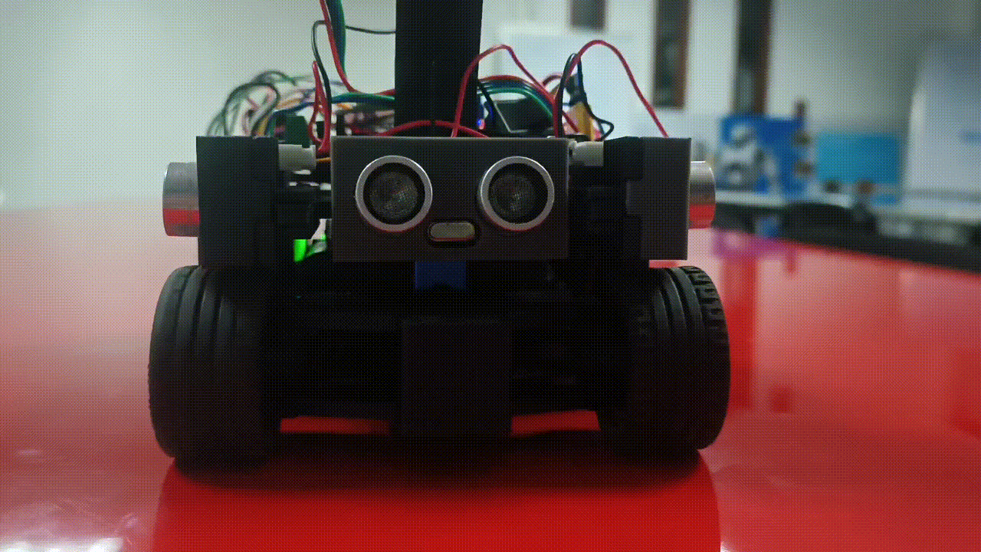
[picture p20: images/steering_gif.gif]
Sistema de Dirección Ackermann Positivo
  
  <br>
  <em><sub style="font-size: 0.85em; color: #8b949e;">Comportamiento dinámico del sistema Ackermann en curva</sub></em>
</p>

<h3>Ecuaciones Fundamentales</h3>

<div style="display: flex; gap: 15px; margin: 15px 0;">
  <div style="flex: 1; background-color: #161b22; border: 1px solid #30363d; border-radius: 6px; padding: 15px;">
    <h4 style="margin-top: 0; color: #58a6ff;">1. Geometría de Giro</h4>
    <p align="center" style="font-size: 1.1em; color: #f0f6fc;">
      $$\cot(\theta_o) - \cot(\theta_i) = \frac{W}{L}$$
    </p>
    <ul style="margin-bottom: 0; padding-left: 20px; font-size: 0.9em; color: #c9d1d9;">
      <li><strong>W:</strong> Ancho de vía (distancia entre pivotes de dirección).</li>
      <li><strong>L:</strong> Batalla (distancia entre ejes).</li>
    </ul>
  </div>

  <div style="flex: 1; background-color: #161b22; border: 1px solid #30363d; border-radius: 6px; padding: 15px;">
    <h4 style="margin-top: 0; color: #58a6ff;">2. Relación de Velocidades</h4>
    <p align="center" style="font-size: 1.1em; color: #f0f6fc;">
      $$\frac{\omega_o}{\omega_i} = \frac{R + W/2}{R - W/2}$$
    </p>
    <ul style="margin-bottom: 0; padding-left: 20px; font-size: 0.9em; color: #c9d1d9;">
      <li><strong>&omega;<sub>o</sub> / &omega;<sub>i</sub>:</strong> Vel. angular rueda exterior / interior.</li>
      <li><strong>R:</strong> Radio de giro al centro del eje posterior.</li>
    </ul>
  </div>
</div>

<div style="display: flex; gap: 15px; margin: 15px 0;">
  <div style="flex: 1; background-color: #161b22; border: 1px solid #30363d; border-radius: 6px; padding: 15px;">
    <h4 style="margin-top: 0; color: #58a6ff;">3. Radio Efectivo de Giro (R)</h4>
    <p align="center" style="font-size: 1.1em; color: #f0f6fc;">
      $$R = \frac{L}{\tan(\delta)} \quad \text{ó} \quad R = \frac{L}{\sin(\delta_i)} - \frac{W}{2}$$
    </p>
    <ul style="margin-bottom: 0; padding-left: 20px; font-size: 0.9em; color: #c9d1d9;">
      <li><strong>R:</strong> Distancia desde el ICR (Centro Instantáneo de Rotación) al centro del eje trasero.</li>
      <li><strong>&delta;:</strong> Ángulo equivalente de rueda equivalente central.</li>
    </ul>
  </div>

  <div style="flex: 1; background-color: #161b22; border: 1px solid #30363d; border-radius: 6px; padding: 15px;">
    <h4 style="margin-top: 0; color: #58a6ff;">4. Ángulo Medio de Dirección (&delta;)</h4>
    <p align="center" style="font-size: 1.1em; color: #f0f6fc;">
      $$\delta = \arctan\left(\frac{2 \cdot L \cdot \sin(\theta_i) \cdot \sin(\theta_o)}{L (\sin(\theta_i) + \sin(\theta_o))}\right)$$
    </p>
    <ul style="margin-bottom: 0; padding-left: 20px; font-size: 0.9em; color: #c9d1d9;">
      <li><strong>&delta;:</strong> Ángulo global de orientación de la trayectoria utilizado por la IMU / Navegación.</li>
    </ul>
  </div>
</div>

<hr style="border-color: #30363d; margin: 25px 0;">

<h3>Rediseño Evolutivo de los Nudillos de Dirección</h3>

<p>
  El diseño mecánico de los nudillos de dirección de <em>Heimdall</em> atravesó una reingeniería clave para corregir fallos estructurales severos detectados durante las pruebas dinámicas.
</p>

<!-- Galería Dinámica - Sistema Anterior -->
<div style="background-color: #161b22; border: 1px solid #f85149; border-radius: 8px; padding: 15px; margin-bottom: 20px;">
  <h4 style="margin-top: 0; color: #f85149; display: flex; align-items: center; gap: 8px;">
    Sistema Anterior: Pivotes Independientes Simulados
  </h4>
  <p style="font-size: 0.95em; color: #c9d1d9; margin-bottom: 12px;">
    Inicialmente, los nudillos se fijaban con dos tornillos de cabeza redondeada independientes para simular el comportamiento de una rótula <i>Rod End</i> y permitir el pivoteo libre. No obstante, las vibraciones y el par del motor desfasaban continuamente estos tornillos de sus alojamientos, provocando que la rueda se saliera por completo del chasis e incapacitara al robot.
  </p>
  <div style="display: flex; gap: 10px; justify-content: center; flex-wrap: wrap;">
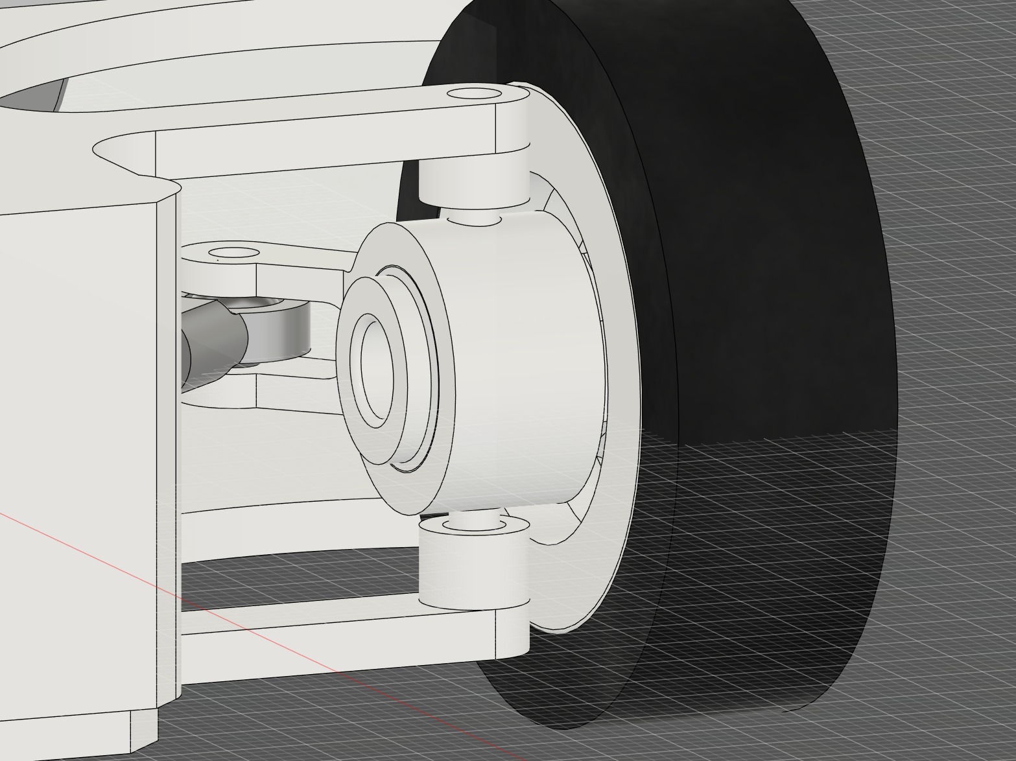
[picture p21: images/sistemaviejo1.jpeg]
Corte del sistema viejo
    
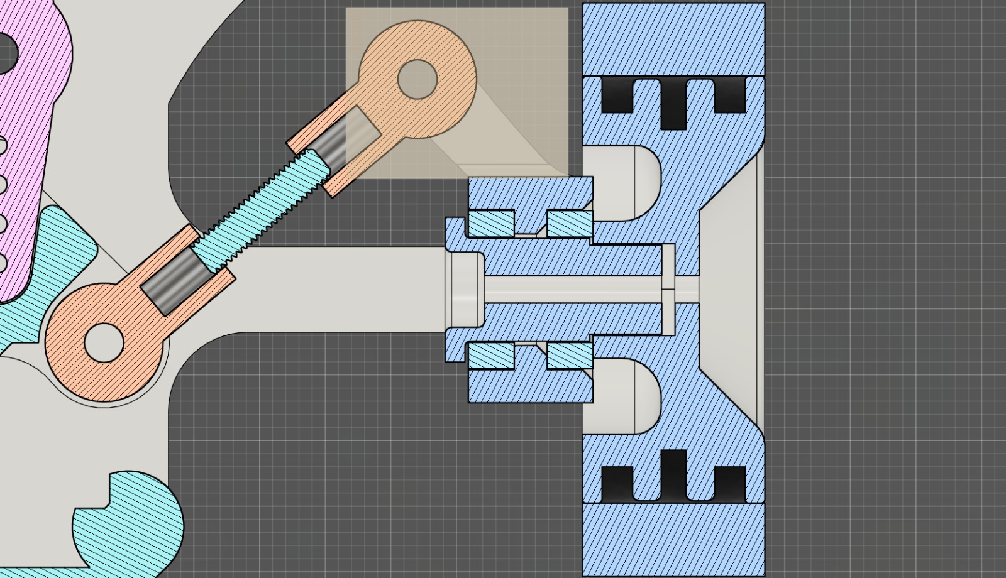
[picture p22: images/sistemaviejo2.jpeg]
Vista de sección sistema viejo
    
  </div>
</div>

<!-- Galería Dinámica - Sistema Nuevo -->
<div style="background-color: #161b22; border: 1px solid #3fb950; border-radius: 8px; padding: 15px; margin-bottom: 20px;">
  <h4 style="margin-top: 0; color: #3fb950; display: flex; align-items: center; gap: 8px;">
    Sistema Optimizado: Tornillo Pasante Continuo
  </h4>
  <p style="font-size: 0.95em; color: #c9d1d9; margin-bottom: 12px;">
    Se reemplazaron ambos tornillos redondeados por un <b>único tornillo pasante central</b> que atraviesa completamente ambas caras del chasis y el nudillo. Para lograrlo, los rodamientos de la rueda se trasladaron directamente hacia el propio <b>rin/rim</b> (dejando una abertura con perno de sujeción). Esta solución eliminó por completo el juego mecánico, reforzó la rigidez estructural y conservó la fluidez de viraje.
  </p>
  <div style="display: flex; gap: 10px; justify-content: center; flex-wrap: wrap;">
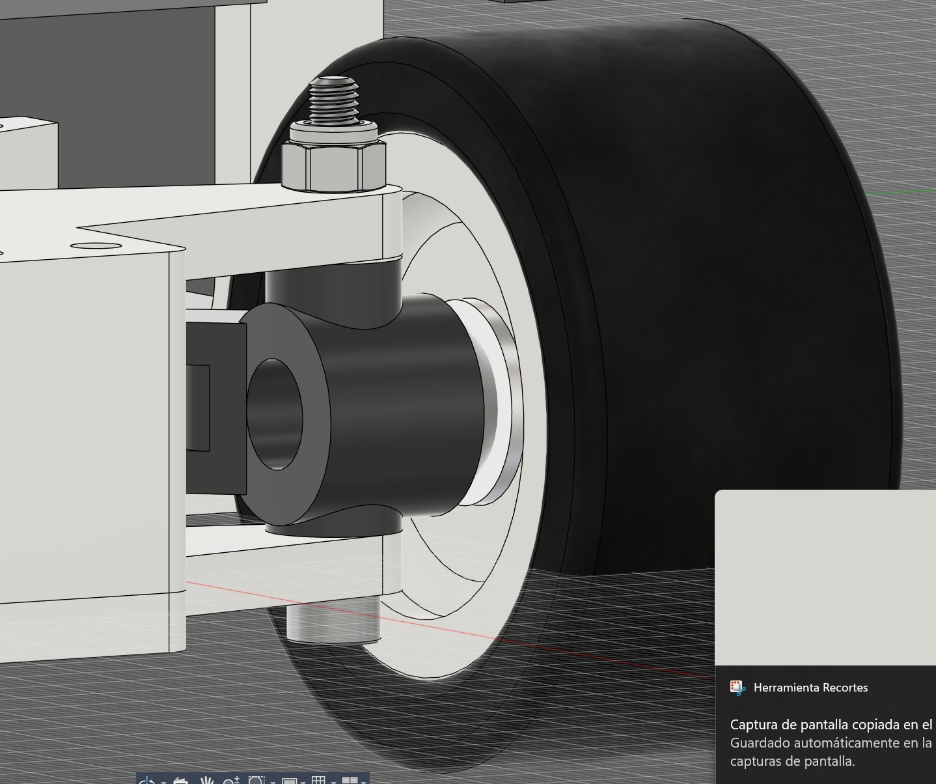
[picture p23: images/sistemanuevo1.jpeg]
Render 3D sistema nuevo
    
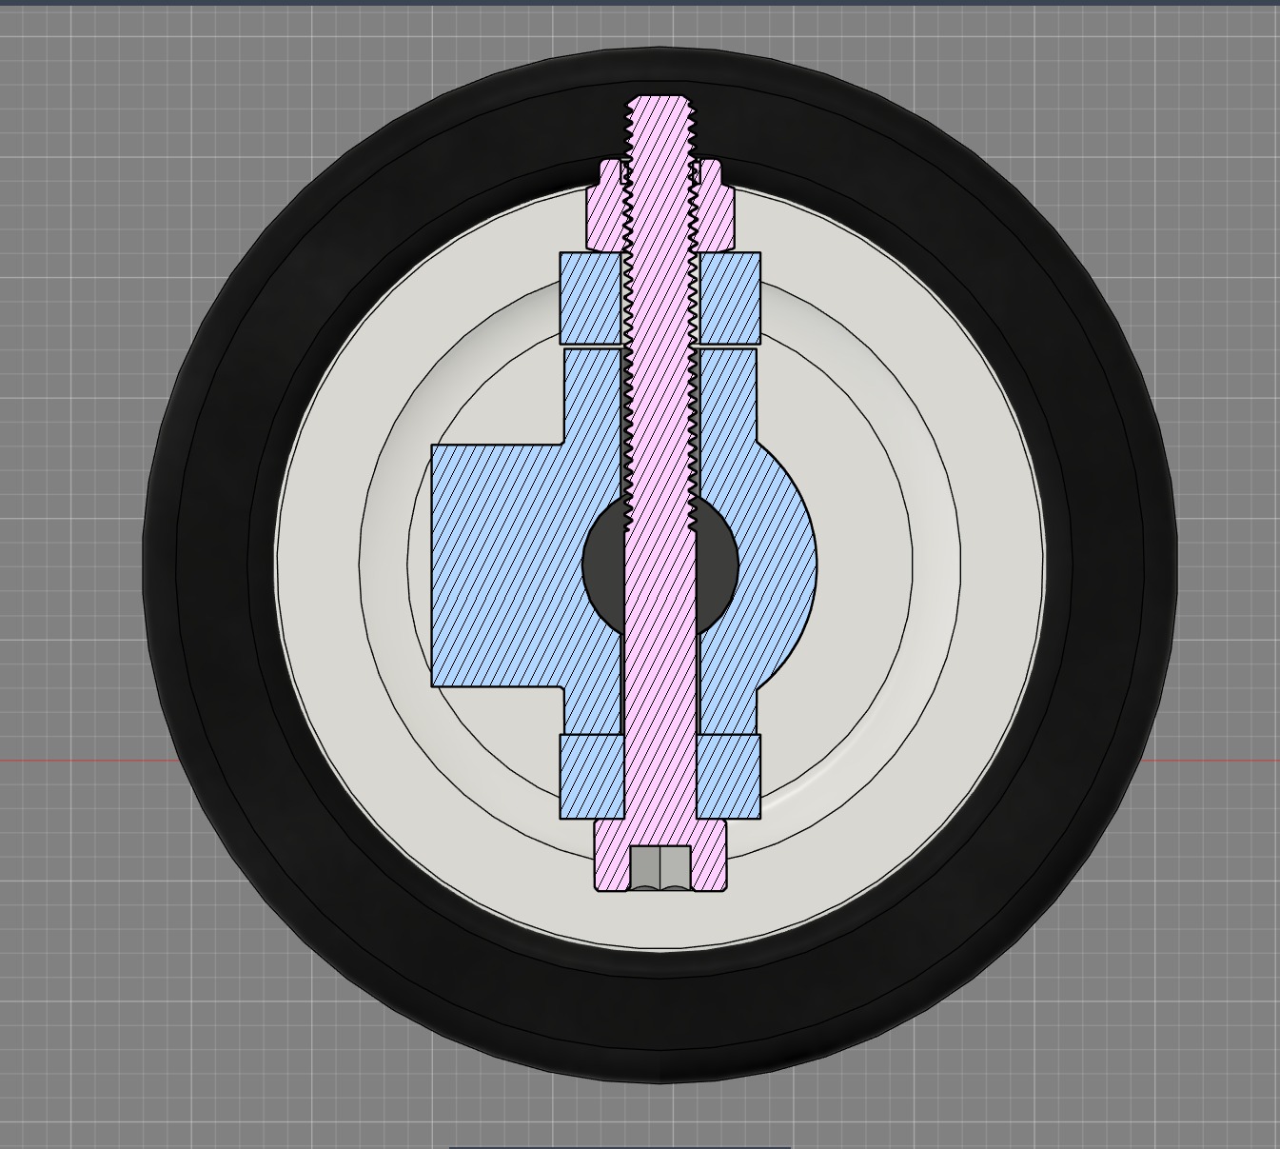
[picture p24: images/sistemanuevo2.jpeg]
Corte frontal del rim y tornillo
    
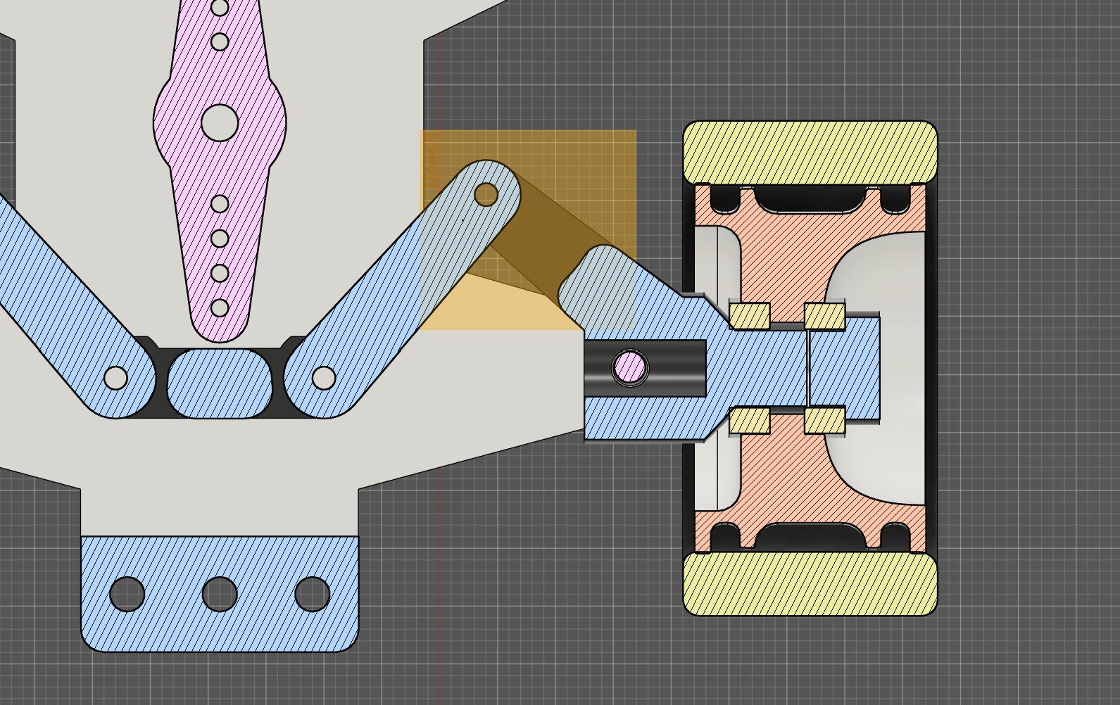
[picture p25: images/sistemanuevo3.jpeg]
Corte superior de la transmisión
    
  </div>
</div>

<hr style="border-color: #30363d; margin: 25px 0;">

<!-- Comparativo Resumido -->
<table width="100%" style="border-collapse: collapse; margin: 15px 0; border: 1px solid #30363d; font-size: 14px;">
  <thead style="background-color: #161b22; color: #f0f6fc;">
    <tr>
      <th style="padding: 10px; border: 1px solid #30363d; text-align: left;">Parámetro</th>
      <th style="padding: 10px; border: 1px solid #30363d; text-align: left; color: #f85149;">Diseño Anterior</th>
      <th style="padding: 10px; border: 1px solid #30363d; text-align: left; color: #3fb950;">Diseño Actual (Reforzado)</th>
    </tr>
  </thead>
  <tbody>
    <tr>
      <td style="padding: 10px; border: 1px solid #30363d;"><b>Pivote Principal</b></td>
      <td style="padding: 10px; border: 1px solid #30363d;">2 tornillos cortos independientes.</td>
      <td style="padding: 10px; border: 1px solid #30363d;"><b>Tornillo pasante continuo</b> de lado a lado.</td>
    </tr>
    <tr>
      <td style="padding: 10px; border: 1px solid #30363d;"><b>Rodamientos</b></td>
      <td style="padding: 10px; border: 1px solid #30363d;">Alojados dentro del nudillo.</td>
      <td style="padding: 10px; border: 1px solid #30363d;">Reubicados directamente en el <b>Rin/Rim</b>.</td>
    </tr>
    <tr>
      <td style="padding: 10px; border: 1px solid #30363d;"><b>Estabilidad</b></td>
      <td style="padding: 10px; border: 1px solid #30363d;">Holgura constante y riesgo de desprendimiento.</td>
      <td style="padding: 10px; border: 1px solid #30363d;">Alineación perfecta y rigidez estructural extra.</td>
    </tr>
  </tbody>
</table>

<hr style="border-color: #30363d; margin: 25px 0;">

<h3>Análisis de Fuerzas y Fenómenos Dinámicos</h3>

```mermaid
flowchart LR
    A["Motor de Tracción"] --> B["Diferencial"]
    B --> C["Semieje der. / Rueda ext. ωₒ"]
    B --> D["Semieje izq. / Rueda int. ωᵢ"]
    C --> E["Fuerza de Tracción Vectorial ↑"]
    D --> F["Ángulo de Giro Ackermann θᵢ > θₒ"]
    E & F --> G["Estructura del Chasis"]
    G --> H{"¿Flexión o Desfase?"}
    H -->|"Sí (Sistema Viejo)"| I["Pérdida de Geometría e Incapacitación"]
    H -->|"No (Sistema Pasante)"| J["Trayectoria Eficiente y Controlada"]
```

> [!WARNING]
> ### Inconvenientes Críticos y Riesgos Detectados en Pruebas Prácticas
>
> 1. **Paradox Steering (Dirección Paradójica):**
>    * **Causa:** Cuando la rueda interior pierde adherencia, el par de tracción vence al ángulo de giro e intenta rectificar la dirección del robot en sentido opuesto al trazo requerido.
>    * **Solución:** Control electrónico de torque diferencial (freno vectorial) y ajuste de geometría en los brazos de dirección.
>
> 2. **Fatiga Mecánica y Desfase en Nudillos:**
>    * **Causa:** La combinación de par motor + ángulo $\theta_i$ máximo ejercía un brazo de palanca crítico sobre los pivotes independientes, desarticulando los tornillos de fijación.
>    * **Solución:** Implementación de tornillo pasante continuo de extremo a extremo y relocalización de los rodamientos directamente en el hub/rin de la rueda.
>
> 3. **Holgura por Desgaste Abración en Puntos de Pivote:**
>    * **Causa:** El uso de **PETG-CF (PETG reforzado con fibra de carbono)** aporta una rigidez estructural y resistencia térmica excepcionales, pero las microfibras expuestas generan una superficie abrasiva que degrada las zonas de fricción directa en los ejes si no existe un buje metálico intermediario.
>    * **Solución:** Inserción de casquillos/bujes metálicos (bronce/latón) en los orificios del nudillo de PETG-CF y calibración mediante rótulas roscadas ajustables.
>
> 4. **Pérdida de Adherencia en Eje Delantero (Understeer/Subviraje):**
>    * **Causa:** Transferencia de masa desfavorable hacia el eje posterior durante aceleraciones bruscas, restando carga normal sobre la dirección.
>    * **Solución:** Redistribución de masa pesada (batería) hacia la sección central-delantera y optimización del perfil de aceleración mediante rampas en el software.

<hr style="border-color: #30363d; margin: 25px 0;">

> [!TIP]
> ### Recomendaciones Técnicas para Ajustes y Uso de PETG-CF
>
> * **Optimización de Impresión en PETG-CF:** Imprimir con boquilla de acero endurecido o rubí ($\ge 0.4\text{ mm}$), orientar las capas de las solapas de dirección de forma paralela a los esfuerzos torsionales para maximizar la adhesión entre capas y evitar fracturas frágiles por fricción.
> * **Inspección de Convergencia (Toe-in/Toe-out):** Verificar con galga o plantilla láser que las ruedas delanteras mantengan un ángulo neutro en recta para evitar desgaste prematuro y resistencia al avance.
> * **Verificación de Par de Apriete:** Utilizar tuercas de seguridad con inserto de nylon (*Nyloc*) en el tornillo pasante de los nudillos para evitar el aflojamiento provocado por las vibraciones continuas.
> * **Lubricación en Uniones PETG-CF / Metal:** Usar grasa de litio sintética o lubricante seco de PTFE en las zonas donde la fibra de carbono del PETG-CF esté en contacto con elementos mecánicos móviles.

<hr style="border-color: #30363d; margin: 25px 0;">

<h3>Soluciones de Ingeniería y Matriz de Optimización</h3>

| Componente | Innovación Mecánica / Electrónica | Riqueza Técnica / Modificación | Beneficio Directo |
| :--- | :--- | :--- | :--- |
| **Cuadro / Chasis** | Subchasis desmontable de rigidez variable. | Puntos de anclaje integrados para eje pasante vertical y distribución modular de peso. | Permite ajustes rápidos en boxes y absorbe las cargas horizontales sin deformar la estructura central. |
| **Diferencial / Tracción** | Control electrónico vectorial con mapeo de giro. | Regulación de PWM diferencial basada en la lectura en tiempo real del ángulo de dirección ($\theta_i$, $\theta_o$). | Maximiza la tracción en curva, elimina el *Paradox Steering* y desestabilizaciones de trayectoria. |
| **Brazos de Dirección** | Linkage Ackermann de alta precisión con rótulas roscadas. | Tirantes ajustables en longitud mediante rosca fina pasante (macho/hembra). | Compensa tolerancias de manufactura en PETG-CF y permite calibrar milimétricamente el valor de $W/L$. |
| **Nudillos de Dirección** | Eje pasante continuo en **PETG-CF** y rodamientos desplazados al Rin. | Pasador M3/M4 de alta tenacidad en solapas rígidas de composite con bearings directamente alojados en el rim. | Elimina por completo el juego mecánico, soporta elevadas cargas de par torsional y previene el desprendimiento de las ruedas. |
| **Puntos de Pivote** | Casquillos metálicos anticorrosivos (*Bushing/Bearings*). | Casquillos de latón/bronce insertados a presión en las caras de fricción para aislar la abrasión del composite. | Elimina el desgaste abrasivo inter-capa de la fibra de carbono, reduce la fricción y prolonga la vida útil del sistema. |

<p align="center">
  <a href="https://postimg.cc/8syssXPz">
    Geometría de giro de Ackermann
  </a>
</p>

## 2.6 Piezas de Mecanica

El núcleo de la movilidad de nuestro robot reside en un subsistema mecánico de transmisión y tracción meticulosamente diseñado. Cada componente ha sido fabricado y seleccionado de forma personalizada para optimizar el espacio, la transferencia de potencia y la eficiencia dinámica del prototipo. 

A continuación, se desglosa cómo cada pieza clave se integra en la arquitectura de ingeniería del robot **Heimdall**:

## 2.6.1 Diferencial y Eje de Transmisión Impreso en 3D

<table style="border: 1px solid #30363d; border-collapse: collapse; width: 100%; background-color: #161b22; border-radius: 8px; overflow: hidden; margin-bottom: 25px;">
  <tr>
    <td width="38%" align="center" style="border: none; padding: 15px; vertical-align: middle; background-color: #0d1117;">
      <div style="margin-bottom: 15px;">
        <b style="font-size: 12px; display: block; margin-bottom: 6px; color: #58a6ff;">⚙️ Componentes del Diferencial</b>
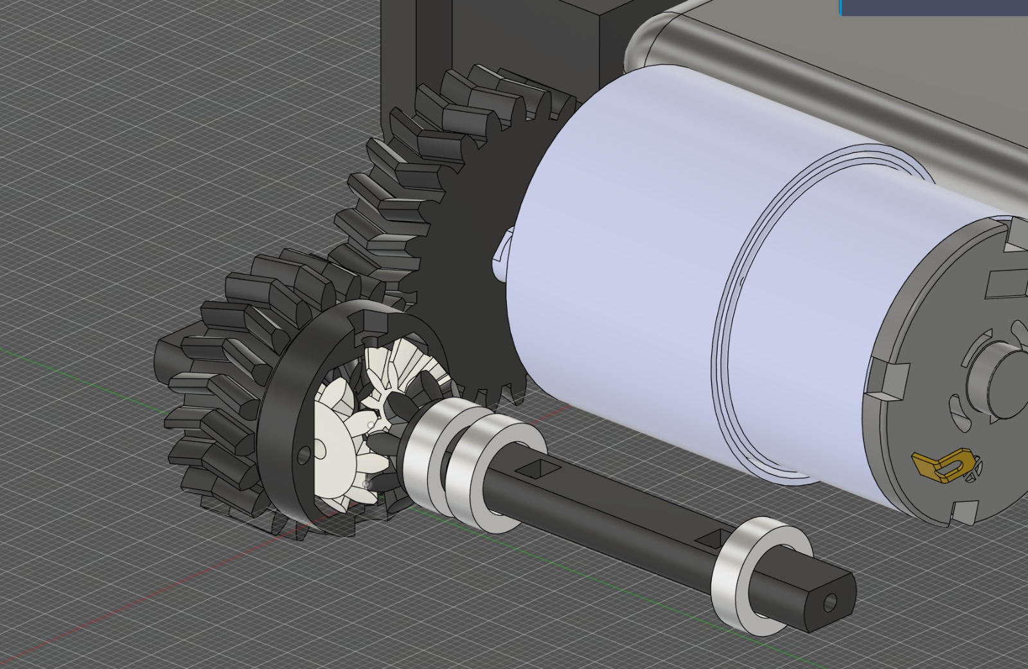
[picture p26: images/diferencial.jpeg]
Componentes del diferencial
        
      </div>
      <div>
        <b style="font-size: 12px; display: block; margin-bottom: 6px; color: #58a6ff;">⚙️ Ensamble Final</b>
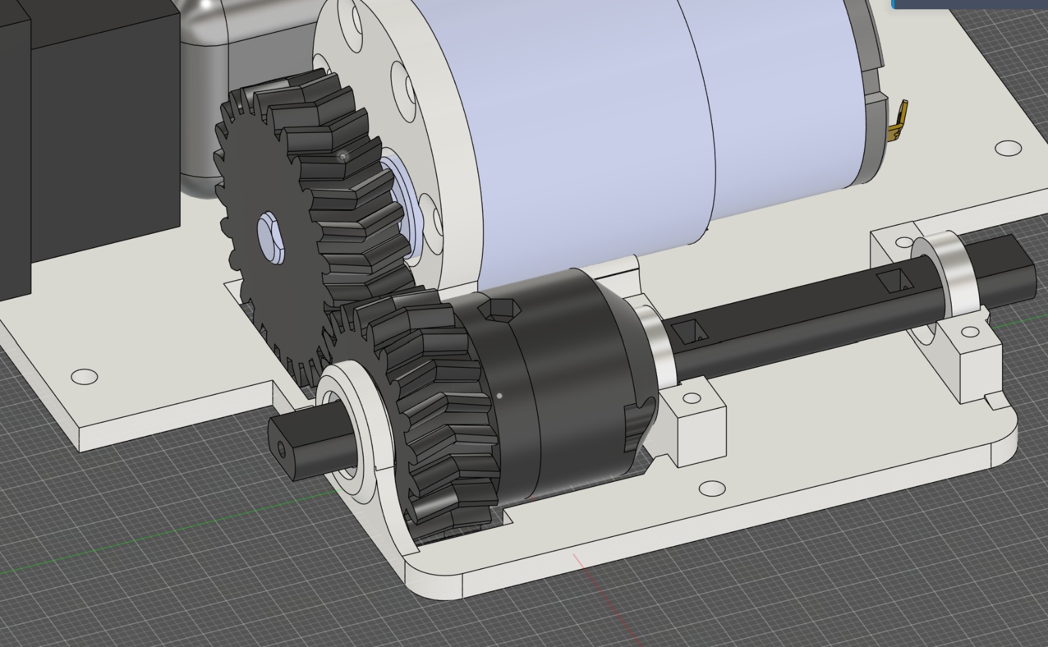
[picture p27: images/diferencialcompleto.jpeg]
Diferencial completo
        
      </div>
    </td>
    <td width="62%" style="border: none; padding: 25px; vertical-align: top; font-family: -apple-system, BlinkMacSystemFont, 'Segoe UI', Helvetica, Arial, sans-serif; text-align: left;">
      <h4 style="margin-top: 0; color: #58a6ff; font-size: 18px; border-bottom: 1px solid #30363d; padding-bottom: 8px; margin-bottom: 15px;">Análisis de la Transmisión y Estabilidad</h4>
      <p style="color: #c9d1d9; font-size: 14px; line-height: 1.6; margin-bottom: 12px;">
        El diferencial se ubica en el eje motriz y permite que las ruedas izquierda y derecha giren a velocidades diferentes al tomar curvas. Esta característica es fundamental para evitar que el robot patine o experimente esfuerzos innecesarios en giros cerrados, manteniendo así la estabilidad incluso durante maniobras agresivas. Su diseño personalizado para el tamaño del robot <b>Heimdall</b> asegura que sea compacto, ligero y proporcional al resto del chasis y ruedas del robot.
      </p>
      <p style="color: #c9d1d9; font-size: 14px; line-height: 1.6; margin-bottom: 12px;">
        Por otro lado, el eje de transmisión conecta directamente la salida del diferencial personalizado a las ruedas motrices. Son responsables de transferir el par del motor generado hacia las ruedas, permitiendo el giro de los neumáticos. Su diseño personalizado garantiza la longitud y resistencia necesarias para soportar las fuerzas de torsión y tracción, sin añadir peso excesivo ni desbalancear el robot.
      </p>
      <p style="color: #c9d1d9; font-size: 14px; line-height: 1.6; margin-bottom: 0;">
        En el caso particular del robot <b>Heimdall</b>, originalmente se consideró una transmisión 4x4. Sin embargo, tras observar las limitaciones en los ángulos de cruce y la maniobrabilidad, se optó por priorizar la movilidad. Por ello, se decidió retirar el eje de transmisión y el diferencial delantero, transformando el robot en un sistema de tracción 4x2.
      </p>
    </td>
  </tr>
</table>

---

## Evolucion del sistema de trasmision 4x2

<p>
  A diferencia de la arquitectura empleada en el diseño anterior del chasis, en esta nueva iteración se logró eliminar por completo el complejo arreglo de ejes y engranajes adicionales que anteriormente se utilizaban para retransmitir la potencia rotacional del motor desde la sección lateral del vehículo. Para conseguir esto, se modificó estratégicamente la posición y orientación del motor dentro de la estructura general, permitiendo acoplar de forma directa su piñón de salida a la caja de la transmisión diferencial. Este cambio geométrico no solo optimizó el uso del espacio interno del robot para la distribución del hardware electrónico, sino que también erradicó puntos de fallas mecánicas recurrentes y redujo la necesidad de mantenimiento preventivo, liberando al sistema de componentes propensos al desgaste como el piñón de ataque intermedio.
</p>

<p>
  Al haber ganado este valioso espacio estructural y haber eliminado una etapa entera de reducción, se aprovechó la oportunidad para rediseñar la cinemática de transmisión, estableciendo una relación de engranajes overdrive de 4:5 (<i>i</i> = 1.25). Esta nueva relación fue seleccionada intencionalmente con el fin de entregar un comportamiento dinámico mucho más estable y lineal durante la navegación autónoma. Al mantener el motor trabajando en una zona eficiente de su curva de torque, el vehículo adquiere una mejor respuesta motriz y una aceleración más firme para responder de manera ágil y controlada ante maniobras bruscas, cambios rápidos de trayectoria en curvas o correcciones repentinas impulsadas por el sistema de control.
</p>

<hr />

<h4>Comparativa Visual de la Transmisión</h4>

<table width="100%">
  <thead>
    <tr>
      <th width="50%" align="center">Prototipo Anterior (Transmisión Lateral)</th>
      <th width="50%" align="center">Prototipo Actual (Acoplamiento Directo)</th>
    </tr>
  </thead>
  <tbody>
    <tr valign="top">
      <td align="center">
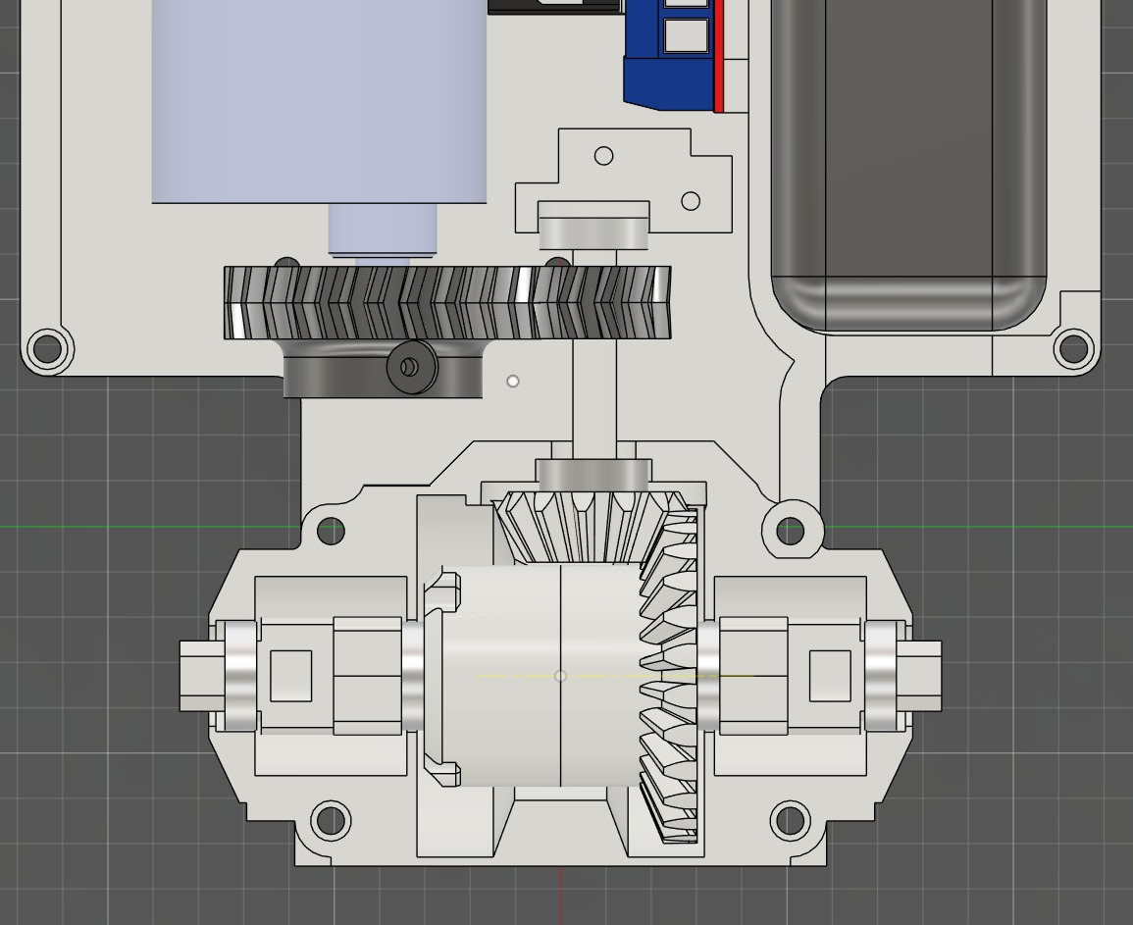
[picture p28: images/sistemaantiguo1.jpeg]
Vista superior sistema antiguo
        
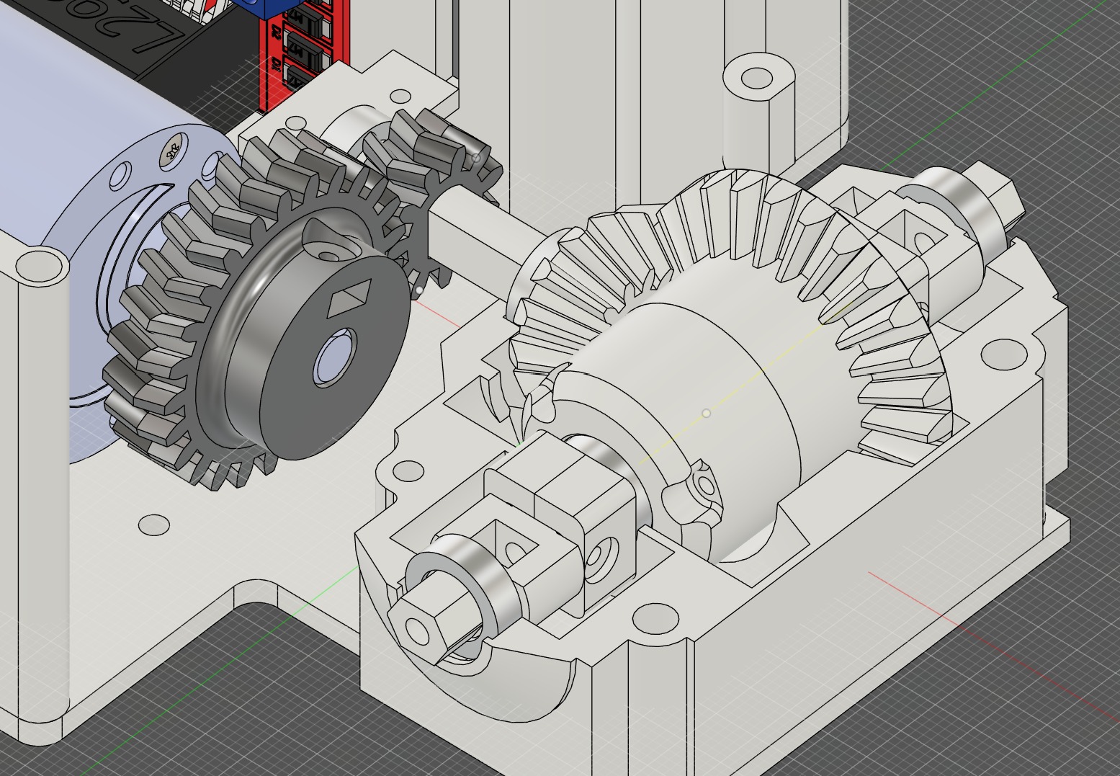
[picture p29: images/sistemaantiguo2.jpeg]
Vista en perspectiva sistema antiguo
        
        <br />
        <small><i>Configuración previa con motor desplazado, eje secundario de transferencia y piñón cónico de ataque.</i></small>
      </td>
      <td align="center">
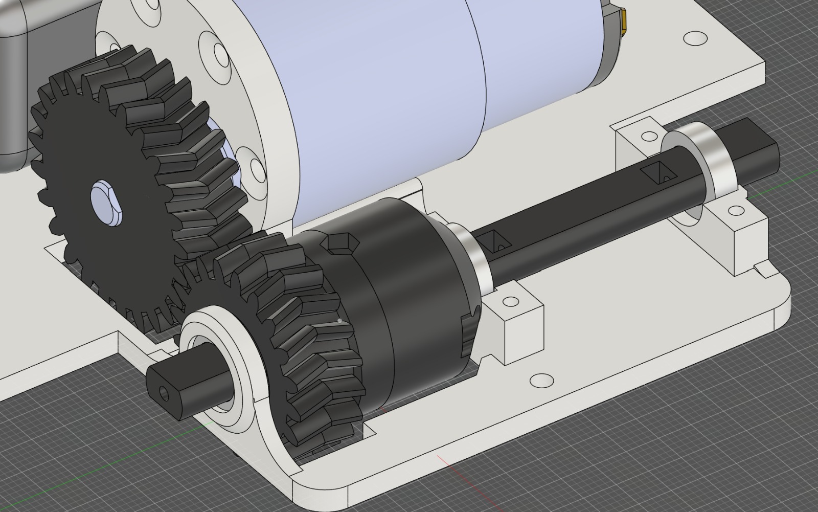
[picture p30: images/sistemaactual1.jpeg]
Vista superior sistema actual
        
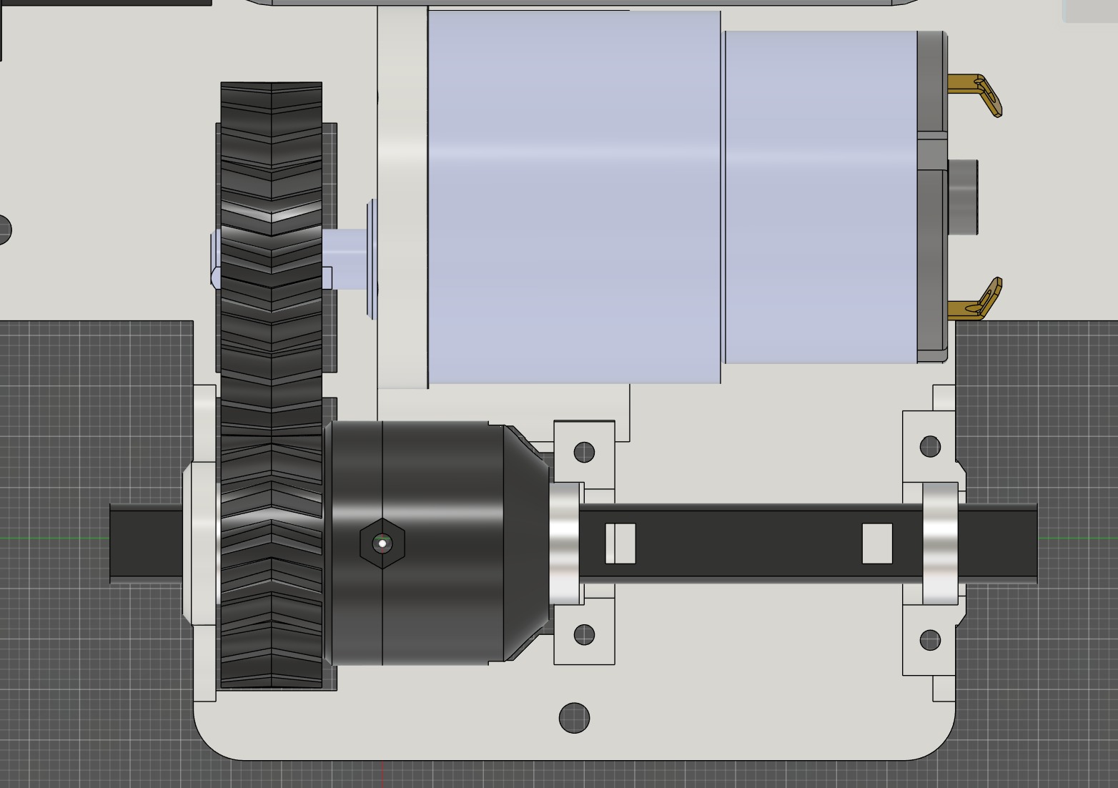
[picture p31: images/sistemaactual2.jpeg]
Vista en perspectiva sistema actual
        
        <br />
        <small><i>Configuración optimizada con motor alineado, acoplamiento directo engranaje-diferencial (4:5) y chasis compacto.</i></small>
      </td>
    </tr>
  </tbody>
</table>

<hr />

## Ventajas y Desventajas de nuestro sistema de transmision 4x2

<table width="100%">
  <tr>
    <th width="50%">Ventajas de la Nueva Arquitectura</th>
    <th width="50%">Desventajas</th>
  </tr>
  <tr valign="top">
    <td>
      <ul>
        <li><b>Ahorro de espacio y peso:</b> Optimización del volumen interno y masa total.</li>
        <li><b>Reducción de piezas móviles:</b> Menor desgaste y puntos de falla.</li>
        <li><b>Mejora de fuerza:</b> Mayor torque para maniobras bruscas.</li>
        <li><b>Reducción de costos:</b> Menor uso de material y piezas.</li>
        <li><b>Mantenimiento simplificado:</b> Acceso rápido a reemplazos.</li>
      </ul>
    </td>
    <td>
      <ul>
        <li><b>Reducción de velocidad final:</b> Menor velocidad máxima teórica.</li>
        <li><b>Menor protección:</b> Mayor exposición a impactos o polvo.</li>
      </ul>
    </td>
  </tr>
</table>

---

## Diferencias mas importantes entre transmisión 4x4 y 4x2 

| Característica | 4x4 (Tracción en las 4 ruedas) | 4x2 (Tracción en 2 ruedas) |
|---|---|---|
| **Motricidad** | Alta, ideal para terrenos irregulares o cruces complejos. | Moderada, suficiente para la mayoría de maniobras en pista controlada. |
| **Ángulo de cruce** | Limitado por la presencia de ejes delanteros. | Mayor libertad de giro y mejor ángulo de cruce. |
| **Estabilidad en curvas** | Más estable en condiciones extremas. | Buena estabilidad, pero depende más del diseño del chasis y el diferencial. |
| **Peso total** | Mayor, por la cantidad extra de componentes (ejes y diferenciales delanteros). | Menor, lo que contribuye a una mejor relación peso-potencia. |
| **Complejidad mecánica** | Más alta; requiere mayor mantenimiento y ajuste. | Más sencilla, facilita el mantenimiento y reduce fallos mecánicos. |
| **Consumo energético** | Más elevado por la transmisión a cuatro ruedas. | Menor, lo que puede aumento de la autonomía. |
| **Aplicación recomendada** | Terrenos difíciles, obstáculos, máxima tracción. | Pistas controladas, mayor maniobrabilidad y agilidad. |

<p align="right">
  <a href="#inicio">Volver Al Inicio</a>
</p>

---

### 2.6.2 **Servomotor INJORA 180°**

<table style="border: 1px solid #444; border-collapse: collapse; width: 100%;">
  <tr style="background-color: rgba(255, 255, 255, 0.05);">
    <td width="350px" align="center" style="padding: 20px; border: 1px solid #444;">
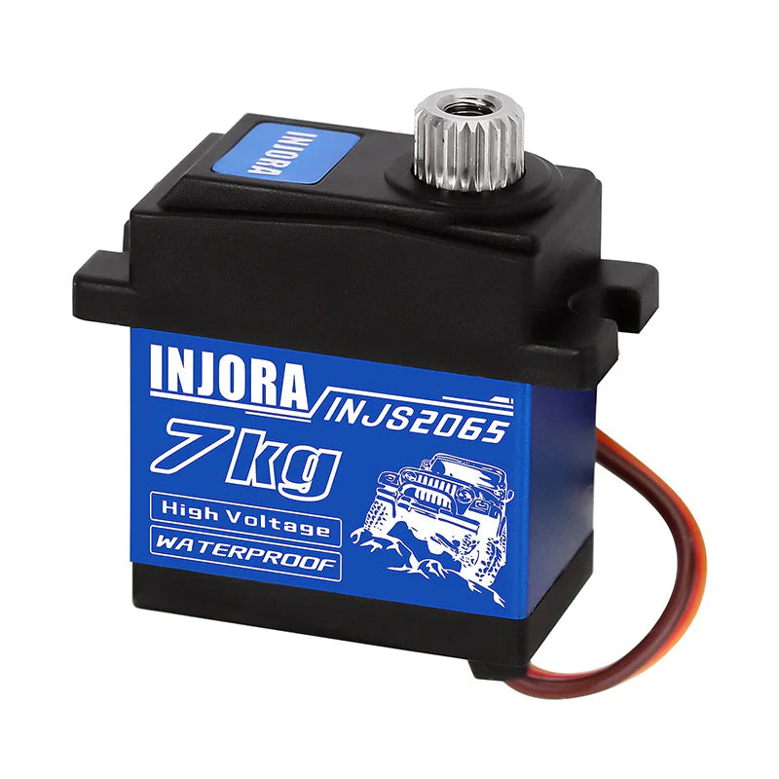
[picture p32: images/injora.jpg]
Injora 7KG 2065
      
    </td>
    <td style="padding: 20px; border: 1px solid #444; vertical-align: top;">
      <h4 style="margin-top: 0;">⚡ Especificaciones</h4>
      <ul>
        <li><b>Tipo:</b> Servo digital de alta precisión.</li>
        <li><b>Banda muerta:</b> 2 µs.</li>
        <li><b>Señal de control:</b> PWM (500-2500 µs, 330 Hz).</li>
        <li><b>Torque de retención (8.4V):</b> 7.0 kg-cm / 97.2 oz-in.</li>
        <li><b>Velocidad (8.4V):</b> 0.06 s/60° (aprox. 150 rpm).</li>
        <li><b>Rodamientos:</b> 1BB (Bolas de acero).</li>
        <li><b>Engranajes:</b> Metálicos para alta durabilidad.</li>
      </ul>
    </td>
  </tr>
</table>

<p style="margin-top: 15px;">
  El servo <b>Injora 2065</b> es un micro servo digital de alto par, diseñado para aplicaciones que demandan movimientos precisos y una respuesta rápida. En <b>Heimdall</b>, este componente es el encargado de ejecutar el sistema de dirección delantera, permitiendo que el robot realice maniobras de esquiva milimétricas gracias a su excelente relación peso-potencia.
</p>

<p><b>Configuración de Software en Heimdall:</b></p>
<p>
  Utilizamos la librería <code>ESP32Servo.h</code> para gestionar la señal PWM en el <b>GPIO 2</b>. Hemos calibrado los límites físicos del mecanismo de dirección para evitar bloqueos mecánicos y optimizar el radio de giro:
</p>

<ul>
  <li><b>Ángulo Central:</b> 96° (Alineación neutra para línea recta).</li>
  <li><b>Rango Máximo (Derecha):</b> 140°.</li>
  <li><b>Rango Mínimo (Izquierda):</b> 50°.</li>
  <li><b>Ángulo de Esquiva:</b> 45° (Giro primario) y 45° (Giro secundario) para maniobras rápidas.</li>
</ul>

<p><b>Ventajas en Competencia:</b></p>
<ul>
  <li><b>Respuesta Dinámica:</b> Su motor de núcleo permite cambios de dirección instantáneos, esenciales cuando la cámara Huskylens2 detecta un bloque a alta velocidad.</li>
  <li><b>Soporte de Voltaje:</b> Al soportar hasta 8.4V, podemos alimentarlo directamente desde el sistema de potencia para maximizar su torque y velocidad.</li>
  <li><b>Maniobras Preventivas:</b> Gracias a su precisión, implementamos ángulos de 20° para las esquivas preventivas, logrando trayectorias más fluidas y evitando colisiones accidentales.</li>
</ul>

<table style="border: 1px solid #444; border-collapse: collapse;">
  <thead style="background-color: rgba(255, 255, 255, 0.1);">
    <tr>
      <th style="padding: 10px; border: 1px solid #444;">🛠️ Herramientas Requeridas</th>
    </tr>
  </thead>
  <tbody>
    <tr>
      <td style="padding: 10px; border: 1px solid #444;">1 × Destornillador hexagonal 1.5 mm</td>
    </tr>
    <tr>
      <td style="padding: 10px; border: 1px solid #444;">1 × Destornillador hexagonal 2.0 mm</td>
    </tr>
  </tbody>
</table>

<br>

<p align="right">
  <a href="#inicio">Volver Al Inicio</a>
</p>

<hr>

### 2.6.3 **Motor Hytech GA37-520**

<table style="border: 1px solid #444; border-collapse: collapse; width: 100%;">
  <tr style="background-color: rgba(255, 255, 255, 0.05);">
    <td width="350px" align="center" style="padding: 20px; border: 1px solid #444;">
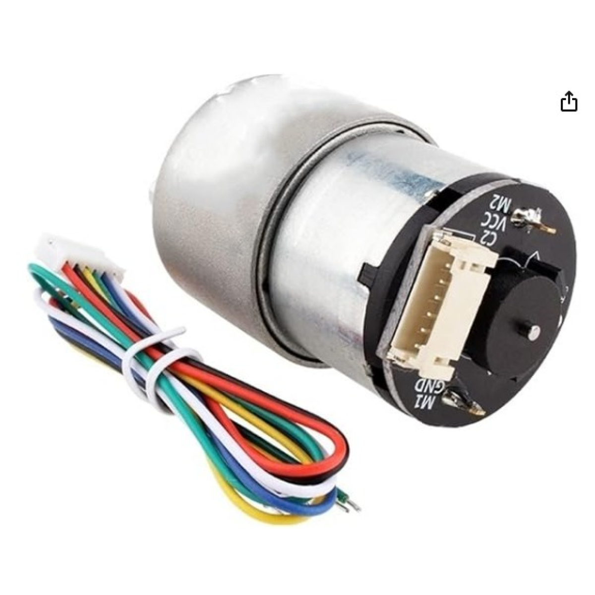
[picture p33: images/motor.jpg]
Motor GA37-520
      
    </td>
    <td style="padding: 20px; border: 1px solid #444; vertical-align: top;">
      <h4 style="margin-top: 0;">⚡ Especificaciones</h4>
      <ul>
        <li><b>Voltaje nominal:</b> 12V DC</li>
        <li><b>Velocidad nominal:</b> 360 RPM</li>
        <li><b>Torque nominal:</b> 4.5 kg.cm</li>
        <li><b>Corriente (Sin carga):</b> ≤ 100mA</li>
        <li><b>Encoder:</b> Magnético de fase dual (Fases A y B)</li>
        <li><b>PPR del Encoder:</b> 11 pulsos por vuelta (330 PPR en eje de salida)</li>
        <li><b>Material:</b> Caja de cambios totalmente metálica</li>
        <li><b>Relación de reducción:</b> 1:30</li>
      </ul>
    </td>
  </tr>
</table>

<p style="margin-top: 15px;">
  El <b>GA37-520</b> es el motor principal de tracción para nuestro robot. A diferencia de otros motores de corriente continua convencionales, este modelo fue elegido específicamente por integrar un <b>encoder magnético</b> de efecto Hall. Esta pieza es fundamental para transformar a <b>Heimdall</b> de un sistema de bucle abierto a uno de <b>lazo cerrado (Closed-Loop)</b>, permitiendo un monitoreo constante del movimiento real del chasis y garantizando que los giros de 90° sean siempre precisos e idénticos.
</p>

> [!TIP]
> **Ventaja del Encoder:** Al tener retroalimentación de las fases A y B, el código puede detectar no solo la velocidad, sino también la dirección del giro y la posición exacta de las ruedas. Esto es vital para corregir desviaciones en tiempo real y asegurar que los giros de 90° sean siempre idénticos, independientemente de la carga o el estado de la batería.

<p><b>¿Por qué decidimos usar este motor?:</b></p>

<ul>
  <li><b>Precisión en Odometría:</b> El encoder permite al ESP32 contar cada pulso del motor, lo que nos otorga la capacidad de medir distancias recorridas en centímetros. Esto es crítico para las fases del desafío donde el robot debe avanzar distancias fijas con error mínimo.</li>
  <li><b>Control de Velocidad PID:</b> Gracias a la lectura constante del encoder, implementamos un algoritmo PID para mantener una velocidad crucero estable, evitando que el robot se acelere o frene bruscamente por irregularidades en la pista.</li>
  <li><b>Robustez Mecánica:</b> Su construcción con engranajes de acero garantiza que el par motor se mantenga constante durante toda la competencia, soportando el estrés de las maniobras de esquiva agresivas.</li>
</ul>

<p><b>Configuración de Pines del Encoder y Motor:</b></p>

<table width="100%" style="border: 1px solid #444; border-collapse: collapse;">
  <thead style="background-color: rgba(255, 255, 255, 0.1);">
    <tr>
      <th style="padding: 10px; border: 1px solid #444;">Pines</th>
      <th style="padding: 10px; border: 1px solid #444;">Función</th>
      <th style="padding: 10px; border: 1px solid #444;">Conexión ESP32</th>
    </tr>
  </thead>
  <tbody>
    <tr>
      <td style="padding: 10px; border: 1px solid #444; text-align: center;">IN1</td>
      <td style="padding: 10px; border: 1px solid #444; text-align: center;">Dirección / PWM</td>
      <td style="padding: 10px; border: 1px solid #444; text-align: center;"><b>GPIO 16</b></td>
    </tr>
    <tr>
      <td style="padding: 10px; border: 1px solid #444; text-align: center;">IN2</td>
      <td style="padding: 10px; border: 1px solid #444; text-align: center;">Dirección / PWM</td>
      <td style="padding: 10px; border: 1px solid #444; text-align: center;"><b>GPIO 17</b></td>
    </tr>
    <tr>
      <td style="padding: 10px; border: 1px solid #444; text-align: center;">VCC Encoder</td>
      <td style="padding: 10px; border: 1px solid #444; text-align: center;">Alimentación Lógica</td>
      <td style="padding: 10px; border: 1px solid #444; text-align: center;">5V DC</td>
    </tr>
    <tr>
      <td style="padding: 10px; border: 1px solid #444; text-align: center;">GND Encoder</td>
      <td style="padding: 10px; border: 1px solid #444; text-align: center;">Tierra</td>
      <td style="padding: 10px; border: 1px solid #444; text-align: center;">GND Negativo</td>
    </tr>
    <tr>
      <td style="padding: 10px; border: 1px solid #444; text-align: center;">Fase A (Blanco)</td>
      <td style="padding: 10px; border: 1px solid #444; text-align: center;">Señal de Pulso</td>
      <td style="padding: 10px; border: 1px solid #444; text-align: center;"><b>GPIO 35</b></td>
    </tr>
    <tr>
      <td style="padding: 10px; border: 1px solid #444; text-align: center;">Fase B (Blanco)</td>
      <td style="padding: 10px; border: 1px solid #444; text-align: center;">Señal de Giro</td>
      <td style="padding: 10px; border: 1px solid #444; text-align: center;"><b>GPIO 34</b></td>
    </tr>
  </tbody>
</table>
<br>

### Calculo de la Reduccion total

Para adaptar la salida del motor a las necesidades del robot, realizamos un cálculo de la reducción total combinando la reducción interna del motor con la de un sistema de engranajes externo. Utilizamos un piñón de ataque estándar (acoplado al eje del motor) y engranajes de 17 y 28 dientes.

La relación de reducción adicional por engranajes se calcula así:
- Si el piñón tiene, por ejemplo, 10 dientes, y el engranaje acoplado tiene 28 dientes, la reducción es 28/10 = 2.8.
- Si se agregan más etapas de engranajes (por ejemplo, usando un engranaje intermedio de 17 dientes), la reducción se multiplica por cada etapa.

La reducción total del sistema es:

```
Reducción total = Reducción interna del motor × (dientes engranaje grande / dientes piñón)
```

En el diseño anterior del tren motriz, la potencia del motor se transmitía a través de un sistema compuesto por dos etapas mecánicas con componentes tipo LEGO:

1. **Primera Etapa (Amplificación Cinemática):**  
   Un piñón conductor de $Z_1 = 36\text{ dientes}$ acoplado a la salida del motor ($n_{\text{motor, ant}} = 550\text{ RPM}$) transmitía su fuerza de rotación a un piñón secundario de $Z_2 = 16\text{ dientes}$. La relación de transmisión teórica de esta etapa ($i_1$) se expresa como:

   $$i_1 = \frac{Z_1}{Z_2} = \frac{36}{16} = 2.25$$

   Considerando las holguras mecánicas y la fricción interdentado, se obtenía un incremento real de $2.11\times$ respecto a la velocidad original del motor, alcanzando una velocidad intermedia ($n_{\text{int}}$) de:

   $$n_{\text{int}} = n_{\text{motor, ant}} \times 2.11 = 550\text{ RPM} \times 2.11 = 1164.7\text{ RPM}$$

2. **Segunda Etapa (Reducción Final):**  
   Posteriormente, esta velocidad intermedia pasaba a través de un piñón de ataque configurado con una relación de reducción de $1 : 2.24$ ($i_2 = \frac{1}{2.24} \approx 0.4464$). La velocidad angular entregada directamente a los ejes de transmisión de las ruedas ($n_{\text{ruedas, ant}}$) se determinaba mediante:

   $$n_{\text{ruedas, ant}} = \frac{n_{\text{int}}}{2.24} = \frac{1164.7\text{ RPM}}{2.24} \approx 521\text{ RPM}$$

   Para las ruedas instaladas de diámetro $D = 33\text{ mm}$ (radio $r = 0.0165\text{ m}$), esta velocidad angular de $521\text{ RPM}$ equivalía a una velocidad lineal teórica de avance ($v_{\text{ant}}$) calculada como:

   $$\omega_{\text{ant}} = 521 \times \frac{2\pi}{60} \approx 54.56\text{ rad/s}$$

   $$v_{\text{ant}} = \omega_{\text{ant}} \cdot r = 54.56\text{ rad/s} \times 0.0165\text{ m} \approx 0.90\text{ m/s}$$

Sin embargo, debido al elevado juego mecánico (*backlash*) y a las pérdidas de torque asociadas al engrane de dos etapas plásticas, este diseño fue sustituido por la configuración actual de transmisión directa al diferencial.

En el sistema actual, un piñón de $Z_{\text{motor}} = 25\text{ dientes}$ acoplado al motor ($n_{\text{motor, act}} = 360\text{ RPM}$) impulsa directamente la caja del diferencial de $Z_{\text{dif}} = 20\text{ dientes}$, estableciendo una relación *overdrive* de $4:5$ ($i_{\text{act}} = 1.25$):

$$i_{\text{act}} = \frac{Z_{\text{motor}}}{Z_{\text{dif}}} = \frac{25}{20} = 1.25$$

$$n_{\text{ruedas, act}} = n_{\text{motor, act}} \times i_{\text{act}} = 360\text{ RPM} \times 1.25 = 450\text{ RPM}$$

Con el mismo diámetro de rueda ($D = 33\text{ mm}$), la velocidad angular final de $450\text{ RPM}$ produce una velocidad lineal estable ($v_{\text{act}}$) de:

$$\omega_{\text{act}} = 450 \times \frac{2\pi}{60} = 15\pi \approx 47.12\text{ rad/s}$$

$$v_{\text{act}} = \omega_{\text{act}} \cdot r = 47.12\text{ rad/s} \times 0.0165\text{ m} \approx 0.778\text{ m/s}$$

Esta transición de $521\text{ RPM}$ ($0.90\text{ m/s}$ con fricción y deslices) a $450\text{ RPM}$ ($0.78\text{ m/s}$ constantes) optimiza la eficiencia del tren de rodaje, elimina la holgura cinemática y garantiza una respuesta rígida para el control de odometría sobre la pista.

#### ¿Por qué es importante la reducción?

Dos palabras clave: `Velocidad` y `Torque`. Al aumentar la reducción, la velocidad de salida disminuye, permitiendo un control más preciso del robot, y paralelamente  La reducción aumenta el torque disponible en las ruedas, lo que mejora la capacidad de mover el robot o superar obstáculos.

### Razones para elegir este motor y sistema de reducción

- **Versatilidad y control:** El motor de 12V es estándar y confiable. La reducción interna más la reducción por engranajes externos se adapta perfectamente a las necesidades del robot.
- **Adaptabilidad:** Cambiando los engranajes externos se puede ajustar fácilmente la velocidad y el torque final.
- **Eficiencia y disponibilidad:** Los componentes son fáciles de conseguir y económicos.

<p align="right">
  <a href="#inicio">Volver Al Inicio</a>
</p>

---

### 2.6.4 **Tornillos, Tuercas de Seguridad y Arandelas (M2 y M3)**

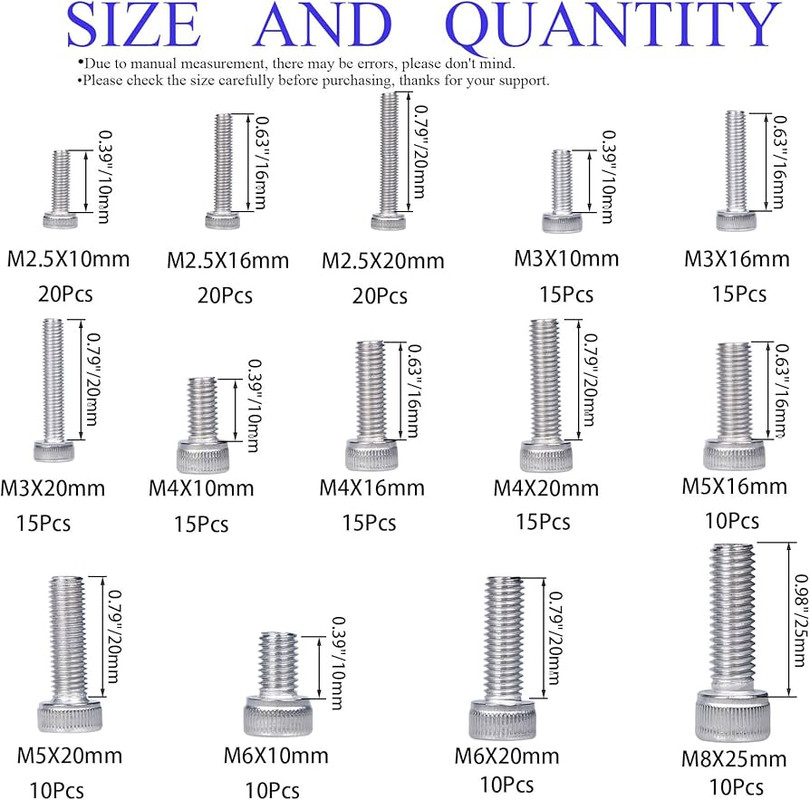
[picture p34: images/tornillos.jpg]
Tornillos m2 y m3


Ya sean M2 o M3, son piezas imprescindibles para la mecanica de nuestro robot, debido a la fijacion de piezas pequeñas, estabilización de componentes, y la garantía de seguridad que otorgan con respecto al uso prolongado del robot ya sea en practicas o en la competición.

Se decidió tomar la decisión de tener tornillos M2 y M3 de forma simultánea para velar por la eficiencia del espacio, para permitir compatibilidad con los componentes más pequeños, y al mismo tiempo para garantizar que los tornillos resistan y permitan estabilidad en el robot.

<p align="right">
  <a href="#inicio">Volver Al Inicio</a>
</p>
     
---

## 3. Apartado Electronico

<p align="justify">
  El apartado electrónico de nuestro robot <b>Heimdall</b> ha sido diseñado bajo una arquitectura modular que prioriza la estabilidad de voltaje y la velocidad de procesamiento. La integración de estos componentes permite que el robot procese datos sensoriales en tiempo real, garantizando una respuesta inmediata ante los desafíos del entorno de la <b>WRO 2026</b>.
</p>

<p><b>La arquitectura se divide en cuatro pilares fundamentales:</b></p>

<ul>
  <li><b>Gestión de Energía:</b> Sistemas de regulación para estabilizar la potencia de las baterías.</li>
  <li><b>Unidad de Procesamiento:</b> Cerebro central encargado de la lógica y visión.</li>
  <li><b>Control de Actuadores:</b> Drivers para el manejo de motores y dirección.</li>
  <li><b>Percepción Sensorial:</b> Sensores ultrasónicos, inerciales y de visión artificial.</li>
</ul>

---

### 3.1 Piezas de Electronica

Por lo tanto hemos decidido usar:

### 3.1.1 **Baterías**

<table>
  <tr>
    <td align="center" width="450">
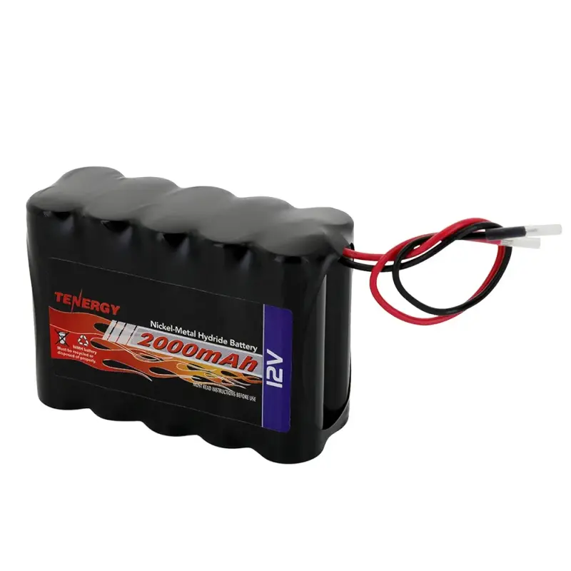
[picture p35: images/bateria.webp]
      
    </td>
    <td>
      <h3>🔋 Especificaciones Técnicas</h3>
      <ul>
        <li><b>Tipo de Química:</b> Níquel-Metal Hidruro (NiMH)</li>
        <li><b>Voltaje Nominal:</b> 12 V DC (10 Celdas AA)</li>
        <li><b>Capacidad / Amperaje:</b> 2000 mAh (2 Ah)</li>
        <li><b>Conector / Salida:</b> Cables desnudos (Adaptable a Molex / XT60)</li>
        <li><b>Tasa de Carga Máxima:</b> 1A - 2A (Recomendada ≤ 1A)</li>
        <li><b>Peso:</b> 225 g</li>
        <li><b>Dimensiones:</b> 2.13 x 2.91 x 1.22 in (54 x 74 x 31 mm)</li>
        <li><b>Fabricante / Modelo:</b> Tenergy / 19676</li>
        <li><b>Vida Útil Promedio:</b> ~500 ciclos completos de carga/descarga</li>
      </ul>
    </td>
  </tr>
</table>

### Justificación de Selección e Integración Mecánica

La elección de la batería **Tenergy NiMH de 12V y 2000 mAh** responde directamente a los requerimientos de consumo dinámico y autonomía extendida que exige la arquitectura electrónica de *Heimdall* en la WRO.

* **Autonomía Prolongada y Eficiencia Energética:** La capacidad de 2000 mAh garantiza una entrega constante de corriente a la etapa de potencia (drivers y motores) y al sistema de control sin caídas de tensión bruscas. La batería mantiene su curva de descarga estable durante sesiones intensas de pruebas continuas en pista, evitando variaciones en la velocidad de avance o en la velocidad del servo de dirección.
* **Resistencia a Recargas Frecuentes (Cero Efecto Memoria):** Su química de Níquel-Metal Hidruro no padece del fenómeno de memorización de carga. Esto nos permite efectuar ciclos de recarga parciales en boxes entre rondas de competencia sin reducir la capacidad útil del pack.
* **Seguridad Química en Entornos de Pruebas:** A diferencia de las baterías LiPo (que presentan riesgos de perforación, inflamación o sobrecarga crítica), las baterías NiMH ofrecen una química robusta ante impactos mecánicos leves e imprecisiones de carga, factor fundamental durante la fase de prototipado del chasis.
* **Factor de Forma y Densidad Energética:** Con un peso optimizado de solo 225 g y un formato sumamente compacto, se integra en la sección media del vehículo sin comprometer el centro de gravedad ni sobrecargar la masa suspendida del eje delantero.

<hr style="border-color: #30363d; margin: 25px 0;">

> [!TIP]
> ### Protocolo de Mantenimiento y Rendimiento en Competición
>
> * **Carga Recomendada:** Emplear un cargador inteligente específico parapacks NiMH de 6V–12V ajustado a **≤ 1A** (0.5C). Esto previene el estrés térmico en las celdas y maximiza su vida útil.
> * **Monitoreo Térmico en Pista:** Supervisar la temperatura del pack tras cada carrera. Si la batería supera los **45 °C**, debe dejar enfriar a temperatura ambiente antes de iniciar un nuevo ciclo de recarga.
> * **Umbral de Descarga Segura:** Detener el uso si el voltaje total del pack cae por debajo de **10.8 V** (~1.08 V por celda). Evitar descargas profundas inferiores a 9.0 V para no polarizar irreversiblemente las celdas internas.
> * **Almacenamiento Prolongado:** Guardar en un lugar fresco y seco (15–25 °C) con una carga del **40% al 60%**. En periodos sin uso, realizar un ciclo completo de carga/descarga de mantenimiento cada 4 semanas.
> * **Aislamiento Antivibración:** Integrar una almohadilla de espuma o goma eva de alta densidad dentro del chasis impreso en PETG-CF para absorber los impactos mecánicos y proteger el wrap térmico del pack.

<p align="right">
  <a href="#inicio">Volver Al Inicio</a>
</p>

---

### 3.1.2 **Step Down**
  
<table>
  <tr>
    <td align="center" width="450">
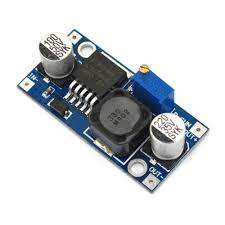
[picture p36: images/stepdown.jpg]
Step Down LM2596
      
    </td>
    <td>
      <h3>⚡ Especificaciones</h3>
      <ul>
        <li>Rango de Entrada: 3.2 – 40 V DC</li>
        <li>Rango de Salida: 1.25 – 37 V DC (Ajustable)</li>
        <li>Corriente de Salida: 2A continuos (hasta 3A Pico con disipador)</li>
        <li>Eficiencia de Conversión: Hasta 92%</li>
        <li>Frecuencia de Conmutación: 150 kHz</li>
        <li>Rizo de Salida: &lt; 30 mV</li>
        <li>Regulación de Carga: ±0.5%</li>
        <li>Regulación de Voltaje: ±2.5%</li>
        <li>Temperatura de Trabajo: -40 °C a +85 °C</li>
        <li>Protecciones: Limitación de corriente y desconexión térmica integrada</li>
        <li>Tipo de Módulo: Regulador de voltaje Step-Down (Buck) no aislado</li>
      </ul>
    </td>
  </tr>
</table>

<p style="margin-top: 15px;">
  El <b>LM2596</b> es un regulador conmutado de tipo <i>Step Down</i> (Buck Converter) DC-DC diseñado para transformar tensiones elevadas en niveles de voltaje inferiores de forma altamente eficiente. Acepta un amplio rango de entrada entre 3.2V y 40V DC, lo cual demuestra una gran versatilidad operativa en la gestión de potencia del robot. Por esta razón, nuestro equipo decidió integrarlo como una etapa de regulación clave para acondicionar la alimentación del circuito lógico.
</p>

<div style="margin-top: 15px; background-color: #161b22; border: 1px solid #30363d; border-radius: 6px; padding: 15px; font-size: 14px; color: #c9d1d9;">
  <p style="margin-bottom: 10px;"><b>Es extremadamente útil para nuestro proyecto debido a su:</b></p>
  <ul style="margin: 0; padding-left: 20px; line-height: 1.6;">
    <li><b>Regulación eficiente de alta conversión:</b> Convierte los ~11.1V / 12V entregados por la fuente principal a los 5V nominales que exige la lógica del sistema. A diferencia de un regulador lineal (como el 7805), el LM2596 no disipa el exceso de voltaje como puro calor, logrando eficiencias de hasta el 92%.</li>
    <li><b>Protección e inmunidad al ruido de motores:</b> Actúa como una barrera entre el sistema lógico y el sistema de potencia, previniendo que las caídas de tensión bruscas causadas por el consumo del motor de tracción reinicien el ESP32 o distorsionen la señal de la HuskyLens 2.</li>
    <li><b>Alta capacidad de corriente activa:</b> Proporciona 2A continuos (con picos tolerados de 3A), suficiente para abastecer en paralelo la demanda simultánea del microcontrolador, los tres sensores ultrasónicos, el servo de dirección y la HuskyLens 2.</li>
    <li><b>Ajuste Fino por Potenciómetro Trimmer:</b> Permite calibrar la salida mediante un potenciómetro multivuelta de precisión para compensar caídas por longitud de cableado y fijar exactamente los voltajes lógicos deseados ($5.0\text{V}$ o $6.0\text{V}$ según los servos requeridos).</li>
    <li><b>Versatilidad de Fuente Alimentadora:</b> Su amplio rango de tolerancia permite probar con diversas químicas de batería (LiPo 2S/3S, baterías selladas o fuentes de taller) sin necesidad de rediseñar el hardware del robot.</li>
  </ul>
</div>

<p><b>Principio de Funcionamiento y Ecuaciones Básicas:</b></p>
<p>
  A diferencia de los reguladores lineales, el LM2596 conmuta un transistor interno a una frecuencia de <b>150 kHz</b>. Al alternar rápidamente entre estado conduciendo y corte, junto con el trabajo de un inductor y un diodo Schottky de alta velocidad, se logra adaptar la energía almacenada reduciendo el voltaje sin perder potencia útil.
</p>

<p>
  La relación ideal de conversión en un regulador <i>Buck</i> se define por el ciclo de trabajo ($D$):
</p>

<p align="center">
  $$V_{\text{salida}} = V_{\text{entrada}} \times D \quad \text{donde} \quad D = \frac{T_{\text{ON}}}{T_{\text{ON}} + T_{\text{OFF}}}$$
</p>

<p>
  Esto garantiza que el calor generado durante la conversión sea mínimo, manteniendo estable el ecosistema de sensores de <b>Heimdall</b> incluso durante carreras prolongadas.
</p>

> [!WARNING]
> - Antes de conectar por primera vez componentes sensibles como el ESP32 o la HuskyLens 2 al regulador, se debe medir con un multímetro la salida de los pines **OUT+** y **OUT-** y girar el potenciómetro fino hasta asegurar un voltaje de $5.0\text{V}$ exactos. Un voltaje descalibrado por encima de $5.5\text{V}$ puede dañar de forma permanente el módulo de visión y los procesadores.

<p><b>Esquema de Distribución de Potencia:</b></p>

<table width="100%" style="border: 1px solid #444; border-collapse: collapse; margin-top: 10px;">
  <thead style="background-color: rgba(255, 255, 255, 0.1);">
    <tr>
      <th style="padding: 10px; border: 1px solid #444;">Terminal LM2596</th>
      <th style="padding: 10px; border: 1px solid #444;">Origen / Destino en el Robot</th>
      <th style="padding: 10px; border: 1px solid #444;">Función en el Sistema</th>
    </tr>
  </thead>
  <tbody>
    <tr>
      <td style="padding: 10px; border: 1px solid #444; text-align: center;"><b>IN+</b></td>
      <td style="padding: 10px; border: 1px solid #444; text-align: center;">Positivo Batería / Interruptor Principal</td>
      <td style="padding: 10px; border: 1px solid #444;">Recibe el voltaje bruto (+7.4V a +12V).</td>
    </tr>
    <tr>
      <td style="padding: 10px; border: 1px solid #444; text-align: center;"><b>IN-</b></td>
      <td style="padding: 10px; border: 1px solid #444; text-align: center;">Negativo Batería (GND General)</td>
      <td style="padding: 10px; border: 1px solid #444;">Tierra común de entrada.</td>
    </tr>
    <tr>
      <td style="padding: 10px; border: 1px solid #444; text-align: center;"><b>OUT+</b></td>
      <td style="padding: 10px; border: 1px solid #444; text-align: center;">Bus Lógico 5V (ESP32, Sensors, HuskyLens 2)</td>
      <td style="padding: 10px; border: 1px solid #444;">Suministra voltaje regulado y filtrado a 5.0V.</td>
    </tr>
    <tr>
      <td style="padding: 10px; border: 1px solid #444; text-align: center;"><b>OUT-</b></td>
      <td style="padding: 10px; border: 1px solid #444; text-align: center;">GND Lógico / Tierra General del Chasis</td>
      <td style="padding: 10px; border: 1px solid #444;">Referencia cero común para todos los módulos.</td>
    </tr>
  </tbody>
</table>

<p align="right">
  <a href="#inicio">Volver Al Inicio</a>
</p>

---

### 3.1.3 **Motor Driver**

<table style="border: 1px solid #444; border-collapse: collapse; width: 100%;">
  <tr style="background-color: rgba(255, 255, 255, 0.05);">
    <td width="350px" align="center" style="padding: 20px; border: 1px solid #444;">
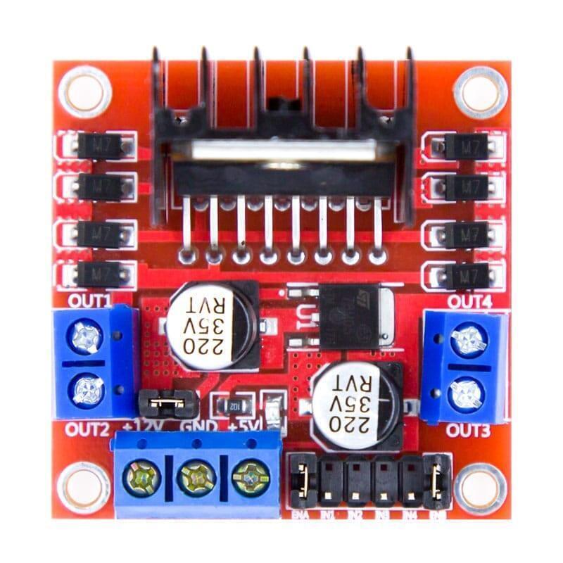
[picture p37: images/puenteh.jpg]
Puente H L298N
      
    </td>
    <td style="padding: 20px; border: 1px solid #444; vertical-align: top;">
      <h4 style="margin-top: 0;">⚡ Especificaciones</h4>
      <ul>
        <li><b>Chip de control:</b> L298N (Doble Puente H de alta potencia).</li>
        <li><b>Voltaje de operación (Motores):</b> 5V a 35V DC.</li>
        <li><b>Corriente máxima (Pico):</b> 2 Amperios por canal.</li>
        <li><b>Corriente continua:</b> 1.2 Amperios por canal.</li>
        <li><b>Voltaje lógico:</b> 5V DC (mediante regulador integrado).</li>
        <li><b>Corriente lógica:</b> 0mA - 36mA.</li>
        <li><b>Potencia máxima:</b> 25 Watts.</li>
        <li><b>Modo de control:</b> PWM (Modulación por ancho de pulsos) y niveles lógicos GPIO.</li>
        <li><b>Temperatura operativa:</b> -20°C a +135°C.</li>
        <li><b>Dimensiones y Peso:</b> 43 x 43 x 27 mm | 30 g aprox.</li>
        <li><b>Extras:</b> Regulador 78M05 integrado de 5V y diodos de protección anti-retorno.</li>
      </ul>
    </td>
  </tr>
</table>

<p style="margin-top: 15px;">
  El driver <b>L298N</b> actúa como el "intermediario de potencia" esencial en la arquitectura de <b>Heimdall</b>. Su función clave es aislar los pines de control del microcontrolador (ESP32) de las altas corrientes que exigen los motores de tracción, transformando las señales de control de baja potencia en corrientes de hasta 2A para permitir cambios de marcha, aceleración progresiva por PWM y frenado activo.
</p>

<p><b>¿Por qué decidimos elegir el L298N sobre otros Motor Drivers?</b></p>
<p>
  Durante la fase de diseño evaluamos distintas alternativas del mercado (como el TB6612FNG o módulos basados en MOSFETs aislados). Seleccionamos el <b>L298N</b> por su alta robustez mecánica, su disipador de calor integrado y, fundamentalmente, por contar con un <b>regulador lineal 78M05 de 5V a bordo</b>.
</p>

| Criterio de Selección | L298N (Elegido) | TB6612FNG | L293D (Shield) |
| :--- | :--- | :--- | :--- |
| **Suministro de 5V Onboard** | **Sí (Regulador 78M05 dedicado)** | No (Requiere regulador externo) | Algunas versiones no integran regulador |
| **Corriente Continua** | **1.2A por canal (Picos de 2A)** | 1.2A por canal (Picos de 3.2A) | 600mA por canal |
| **Disipación Térmica** | **Disipador de aluminio masivo** | Sin disipador (requiere cobre en PCB) | Disipación limitada por encapsulado DIP |
| **Robustez ante Picos** | **Alta (Diodos de protección integrados)** | Media (Sensible a sobrevoltajes de retorno) | Baja |

> [!TIP]
> - El regulador **78M05** integrado en el controlador genera una **salida de 5V DC completamente estable**. Esta línea de alimentación es un punto neurálgico en nuestro robot, ya que alimenta de forma limpia y constante al ESP32 (mediante su pin VIN/5V), a la HuskyLens 2 y a los sensores de ultrasonido, evitando la necesidad de añadir un convertidor Buck externo adicional.

<p><b>Partes Clave del Módulo L298N:</b></p>

<table width="100%" style="border: 1px solid #444; border-collapse: collapse; margin: 15px 0;">
  <thead style="background-color: rgba(255, 255, 255, 0.1);">
    <tr>
      <th style="padding: 10px; border: 1px solid #444; text-align: left;">Componente</th>
      <th style="padding: 10px; border: 1px solid #444; text-align: left;">Función en el Sistema</th>
    </tr>
  </thead>
  <tbody>
    <tr>
      <td style="padding: 10px; border: 1px solid #444;"><b>Puertos de salida (OUT1, OUT2)</b></td>
      <td style="padding: 10px; border: 1px solid #444;">Conexión directa a los bornes del motor principal de tracción de Heimdall.</td>
    </tr>
    <tr>
      <td style="padding: 10px; border: 1px solid #444;"><b>Entradas lógicas (IN1, IN2)</b></td>
      <td style="padding: 10px; border: 1px solid #444;">Reciben los estados lógicos desde el ESP32 para determinar el sentido de giro (Avance / Reversa / Freno).</td>
    </tr>
    <tr>
      <td style="padding: 10px; border: 1px solid #444;"><b>Pin de Habilitación (ENA)</b></td>
      <td style="padding: 10px; border: 1px solid #444;">Recibe la señal **PWM** desde el ESP32 para controlar la velocidad lineal de tracción.</td>
    </tr>
    <tr>
      <td style="padding: 10px; border: 1px solid #444;"><b>Salida Regulada de 5V</b></td>
      <td style="padding: 10px; border: 1px solid #444;">Entrega voltaje regulado a la lógica del sistema (ESP32, HuskyLens 2 y Sensores).</td>
    </tr>
    <tr>
      <td style="padding: 10px; border: 1px solid #444;"><b>Jumper 5V-EN</b></td>
      <td style="padding: 10px; border: 1px solid #444;">Mantiene activo el regulador interno cuando el voltaje de batería principal es de $7.4\text{V} - 12\text{V}$.</td>
    </tr>
  </tbody>
</table>

<p><b>¿Cómo controla el sentido de giro y la velocidad? (Diagrama de Conmutación):</b></p>
<p>
  El chip L298N utiliza cuatro transistores/MOSFETs internos organizados en una topología en H. Dependiendo de las señales enviadas a las entradas <code>IN1</code> e <code>IN2</code>, el flujo de corriente atraviesa el motor en una dirección u otra:
</p>

```text
    [VCC Motor +12V]
           |
   +-------+-------+
   |               |
 [SW1]           [SW3]   <-- Controlados por IN1 e IN2
   |               |
   +---[ MOTOR ]---+
   |               |
 [SW2]           [SW4]
   |               |
   +-------+-------+
           |
         [GND]
```

<p align="right">
  <a href="#inicio">Volver Al Inicio</a>
</p>

---

### 3.1.4 **Sensor de Ultrasonido**

<table style="border: 1px solid #444; border-collapse: collapse; width: 100%;">
  <tr style="background-color: rgba(255, 255, 255, 0.05);">
    <!-- Imagen del Sensor -->
    <td width="350px" align="center" style="padding: 20px; border: 1px solid #444;">
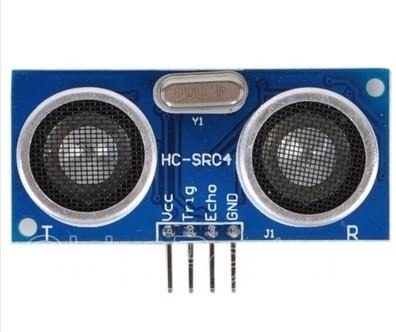
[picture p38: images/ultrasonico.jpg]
HC-SR04
      
    </td>
    <!-- Cuadro de Especificaciones -->
    <td style="padding: 20px; border: 1px solid #444; vertical-align: top;">
      <h4 style="margin-top: 0;">⚡ Especificaciones</h4>
      <ul>
        <li><b>Voltaje de operación:</b> 5V DC</li>
        <li><b>Frecuencia acústica:</b> 40 kHz</li>
        <li><b>Unidades en Heimdall:</b> 3 (Ecosistema de detección periférica)</li>
        <li><b>Librería de control:</b> NewPing (Gestión de triggers no bloqueantes)</li>
        <li><b>Rango de medición:</b> 1cm 357cm</li>
        <li><b>Precisión de resolución:</b> 0.3 cm</li>
        <li><b>Ángulo de detección:</b> < 15°</li>
        <li><b>Protocolo:</b> Pulso TTL de activación (10µs) y respuesta proporcional</li>
      </ul>
    </td>
  </tr>
</table>

<p style="margin-top: 15px;">
  El <b>HC-SR04</b> es un sensor de telemetría acústica diseñado para medir distancias mediante la emisión de ondas ultrasónicas. A diferencia de los sensores ópticos que pueden fallar ante cambios de iluminación, el HC-SR04 procesa el "tiempo de vuelo" (Time of Flight) de una ráfaga sonora, permitiendo que <b>Heimdall</b> conozca su posición exacta respecto a los muros de la pista de forma fiable y constante.
</p>

> [!TIP]
>  - En el codigo recomiendo usar un promedio de las 5 lecturas y que agarre las mas similares para evitar fallos.
>  - Recomiendo el ignorar distancias como 357 por que puede dar falsos picos de lectura.   

<p><b>Ventajas competitivas en la navegación del robot:</b></p>

<ul>
  <li><b>Detección de Obstáculos por Eco:</b> El sensor emite 8 ráfagas de 40 kHz que rebotan en los muros. Al calcular el tiempo que tarda el sonido en regresar, el robot puede "ver" a qué distancia se encuentra de las colisiones sin contacto físico.</li>
  <li><b>Optimización con la libreria NewPing:</b> Implementamos esta librería para gestionar el ecosistema de 3 sensores de forma paralela. NewPing optimiza el ciclo de trabajo del ESP32, descartando ecos residuales y permitiendo una frecuencia de muestreo más alta..</li>
  <li><b>Sustitución en Caliente:</b> Su arquitectura estandarizada permite un reemplazo modular inmediato. En una competencia de alto nivel, la capacidad de reparar el sistema de navegación en segundos ante un fallo eléctrico es una ventaja estratégica clave.</li>
</ul>

<p><b>Principio de Operación Técnica:</b></p>

<p>Para obtener la distancia, el sistema realiza un proceso de cuatro etapas sincronizado por hardware y software:</p>

<ul>
  <li><b>Disparo (Trigger):</b> Se envía un pulso de 10 microsegundos para activar el transductor emisor.</li>
  <li><b>Emisión:</b> El sensor genera automáticamente una ráfaga de ultrasonido inaudible.</li>
  <li><b>Captura (Echo):</b> El receptor detecta la onda reflejada y pone el pin de Echo en nivel alto.</li>
  <li><b>Cálculo Cinemático:</b> Basándonos en la velocidad del sonido (~340m/s), el código transforma el tiempo medido en una magnitud lineal (cm).</li>
</ul>

<p><b>Cálculo de Distancia y Algoritmo Interno de NewPing:</b></p>

<p>
  La librería <b>NewPing</b> optimiza la lectura del tiempo de vuelo ($t$) eliminando los bloqueos en el hilo de ejecución principal del ESP32. El proceso técnico y la matemática empleada se estructuran de la siguiente manera:
</p>

<ul>
  <li><b>Fase 1: Disparo de precisión:</b> NewPing genera un pulso digital en ALTO de 10 $\mu s$ en el pin <code>Trigger</code> del sensor seleccionado.</li>
  <li><b>Fase 2: Conteo de tiempo ($t$):</b> El transductor ultrasónico envía 8 ráfagas a 40 kHz. En el momento en que se emite la señal, el pin <code>Echo</code> cambia a estado ALTO. NewPing mide la duración exacta en microsegundos ($\mu s$) que el pin permanece en este estado hasta que la señal reflejada regresa.</li>
  <li><b>Fase 3: Conversión mediante Ecuación Física:</b> Sabiendo que la velocidad del sonido a temperatura ambiente es aproximadamente de $343\text{ m/s}$ (o lo que es lo mismo, $0.0343\text{ cm/}\mu s$), la onda recorre la distancia ida y vuelta. Por lo tanto, la fórmula cinemática base es:
    <p align="center">
      $$\text{Distancia (cm)} = \frac{t \times 0.0343}{2}$$
    </p>
  </li>
  <li><b>Fase 4: Simplificación por constante de velocidad (US_ROUNDTRIP_CM):</b> Para evitar realizar operaciones matemáticas en coma flotante en cada iteración del ciclo —lo cual consumiría ciclos innecesarios del microcontrolador— NewPing define internamente una constante basada en el tiempo de viaje de ida y vuelta por centímetro:
    <p align="center">
      $$\text{Constante ID/Vuelta} = \frac{2}{0.0343} \approx 57.57 \space \mu s/\text{cm} \quad \rightarrow \quad \texttt{US\_ROUNDTRIP\_CM} = 57$$
    </p>
    Por consiguiente, la librería ejecuta la distancia mediante una división entera ultra rápida:
    <p align="center">
      $$\text{Distancia (cm)} = \frac{\text{Tiempo de Echo } (t \text{ en } \mu s)}{\text{US\_ROUNDTRIP\_CM}}$$
    </p>
  </li>
  <li><b>Fase 5: Filtrado de Ruido y Ping en Temporizador:</b> En lugar de usar la función bloqueante <code>pulseIn()</code> del entorno tradicional de Arduino, NewPing emplea interrupciones de temporizador por hardware para medir la respuesta del pin <code>Echo</code>. Si el eco excede el tiempo de límite configurado (o no regresa), la librería retorna inmediatamente un valor de $0\text{ cm}$, evitando que el robot se detenga a esperar una señal perdida.</li>
</ul>

<p><b>Distribución de Pines en Heimdall:</b></p>

<table width="100%" style="border: 1px solid #444; border-collapse: collapse;">
  <thead style="background-color: rgba(255, 255, 255, 0.1);">
    <tr>
      <th style="padding: 10px; border: 1px solid #444;">Eje de Detección</th>
      <th style="padding: 10px; border: 1px solid #444;">Pin Trigger</th>
      <th style="padding: 10px; border: 1px solid #444;">Pin Echo</th>
    </tr>
  </thead>
  <tbody>
    <tr>
      <td style="padding: 10px; border: 1px solid #444; text-align: center;"><b>Frontal:</b></td>
      <td style="padding: 10px; border: 1px solid #444; text-align: center;">13</td>
      <td style="padding: 10px; border: 1px solid #444; text-align: center;">12</td>
    </tr>
    <tr>
      <td style="padding: 10px; border: 1px solid #444; text-align: center;"><b>Izquierdo:</b></td>
      <td style="padding: 10px; border: 1px solid #444; text-align: center;">14</td>
      <td style="padding: 10px; border: 1px solid #444; text-align: center;">27</td>
    </tr>
    <tr>
      <td style="padding: 10px; border: 1px solid #444; text-align: center;"><b>Derecho:</b></td>
      <td style="padding: 10px; border: 1px solid #444; text-align: center;">26</td>
      <td style="padding: 10px; border: 1px solid #444; text-align: center;">25</td>
    </tr>
  </tbody>
</table>

<p align="right">
  <a href="#inicio">Volver Al Inicio</a>
</p>

<hr>

### 3.1.5 **Giroscopio**

<table style="border: 1px solid #444; border-collapse: collapse; width: 100%;"> 
  <tr style="background-color: rgba(255, 255, 255, 0.05);"> 
    <td width="350px" align="center" style="padding: 20px; border: 1px solid #444;"> 
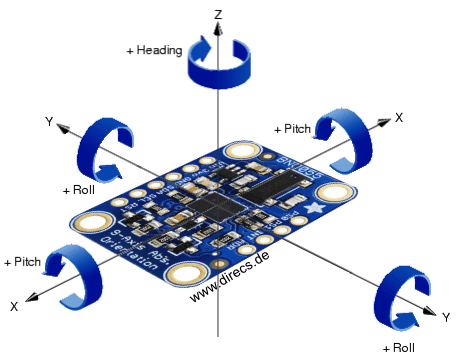
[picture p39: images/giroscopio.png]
BNO055 Sensor
       
    </td> 
    <td style="padding: 20px; border: 1px solid #444; vertical-align: top;"> 
      <h4 style="margin-top: 0;">⚡ Especificaciones</h4> 
      <ul> 
        <li><b>Sensor:</b> IMU de 9 grados de libertad (Acelerómetro + Giroscopio + Magnetómetro)</li> 
        <li><b>Procesador interno:</b> ARM Cortex-M0 (Fusión de datos por hardware)</li> 
        <li><b>Librerías de control:</b> Adafruit_BNO055.h, Adafruit_Sensor.h, utility/imumaths.h</li> 
        <li><b>Rango del Giroscopio:</b> ±125 a ±2000 °/s</li> 
        <li><b>Modos de Operación:</b> NDF, IMU, COMPASS, M4G, NDF_FMC_OFF, NDOF</li> 
        <li><b>Protocolo de comunicación:</b> I2C (Wire.h) / UART</li> 
        <li><b>Voltaje de operación:</b> 3.3V - 5V (mediante regulador integrado en Vin)</li> 
      </ul> 
    </td> 
  </tr> 
</table> 

<p style="margin-top: 15px;"> 
  El <b>BNO055</b> es el sistema de orientación absoluta inercial de nuestro robot. A diferencia de un giroscopio tradicional, integra un microcontrolador de 32 bits que ejecuta algoritmos de fusión de sensores en tiempo real. Esto permite obtener ángulos de Euler directos y cuaterniones para medir el eje Z (yaw) sin sobrecargar el procesador principal, garantizando trayectorias completamente rectas y giros de alta precisión.
</p> 

<p><b>¿Por qué reemplazamos el MPU6050 por el BNO055?</b></p>
<p>
  En las etapas iniciales del desarrollo de Heimdall utilizamos el sensor MPU6050. Sin embargo, migramos al <b>BNO055</b> debido a la necesidad de obtener una mayor precisión de lectura angular y la inclusión de un <b>magnetómetro integrado</b> de 3 ejes. Mientras que el MPU6050 acumula deriva (<i>drift</i>) severa con el tiempo y requiere que el microcontrolador principal ejecute complejos filtros software (Kalman o Complementario), el BNO055 integra un coprocesador ARM Cortex-M0 que realiza la fusión de sensores de 9 grados de libertad por hardware, entregando ángulos de Euler estables y limpios al instante.
</p>

| Criterio de Comparación | Bosch BNO055 | InvenSense MPU6050 |
| :--- | :--- | :--- |
| **Grados de Libertad (DoF)** | **9 DoF** (Acelerómetro + Giroscopio + Magnetómetro) | 6 DoF (Acelerómetro + Giroscopio) |
| **Magnetómetro Integrado** | **Sí** (Permite orientación absoluta con respecto al norte magnético) | No (Propenso a deriva constante en el eje Z / Yaw) |
| **Fusión de Datos (Sensor Fusion)** | **Hardware Onboard (ARM Cortex-M0 interno)** | Requiere software externo / procesado en el ESP32 |
| **Precisión de Lectura (Yaw/Z)** | **Alta (Ángulos absolutos sin acumulativo de deriva)** | Media-Baja (Alta deriva con el paso del tiempo) |
| **Calibración y Offsets** | **Autocalibración activa y exportación directa de offsets** | Requiere rutinas manuales extensas al iniciar |
| **Carga de Cómputo en el ESP32** | **Nula** (Entrega Euler/Cuaterniones listos) | Alta (Requiere procesar matrices y filtros software) |

<p><b>¿Por qué decidimos usar este sensor y las librerías de Adafruit?</b></p> 

<ul> 

  <li><b>Fusión de Datos Inteligente (Sensor Fusion):</b> Al combinar acelerómetro, giroscopio y magnetómetro de forma interna, calcula la orientación absoluta eliminando prácticamente todo el "drift" (deriva) de forma automática.</li> 

  <li><b>Ahorro de Carga de Procesamiento:</b> Las librerías <b>Adafruit_BNO055.h</b> y <b>utility/imumaths.h</b> entregan vectores matemáticos listos (grados o radianes) mediante estructuras directas de tipo vector o cuaternión, sin requerir cálculos complejos de filtros complementarios o de Kalman en el ESP32.</li> 

  <li><b>Integración Directa con PID:</b> Los datos limpios de orientación alimentan nuestro algoritmo PID, permitiendo correcciones instantáneas frente a desvío de trayectoria, deslizamientos en pista o perturbaciones mecánicas.</li> 

</ul> 

> [!TIP] 
> - El BNO055 cuenta con un sistema de autocalibración constante para sus tres sensores (System, Gyro, Accel, Mag) clasificado del 0 al 3. 
> - Puedes guardar los datos de offsets de calibración directamente en la memoria Flash o EEPROM del ESP32 tras la ronda de práctica. Al iniciar en competencia, el código recupera los offsets al instante, logrando una preparación inmediata sin esperar tiempos prolongados de calibración en la línea de salida.

> [!WARNING] 
> - Asegúrate de que el sensor no esté expuesto a interferencias magnéticas fuertes (motores de alta potencia muy cercanos sin blindaje), ya que el magnetómetro integrado podría afectar temporalmente la precisión del yaw si se opera en modo NDOF. 
> - En caso de requerir máxima estabilidad en entornos con ruido magnético, se recomienda configurar el sensor en modo **IMU** (utilizando solo Acelerómetro + Giroscopio para la fusión).

<p><b>Proceso de Calibración Aplicado en el Robot:</b></p>

<p>
  Para garantizar la máxima precisión en el control de trayectoria de <b>Heimdall</b>, ejecutamos una rutina de calibración práctica de los tres sensores internos (acelerómetro, giroscopio y magnetómetro) midiendo los estados de auto-calibración en una escala de <b>0 (sin calibrar)</b> a <b>3 (completamente calibrado)</b>:
</p>

<ul>
  <li><b>Giroscopio (Gyro - Nivel 3):</b> Colocamos el chasis sobre una superficie completamente nivelada y firme sin moverlo durante 3 segundos para fijar el offset del cero absoluto.</li>
  <li><b>Acelerómetro (Accel - Nivel 3):</b> Orientamos la estructura en 6 posiciones estáticas distintas (sobre sus ruedas, de lado y verticalmente) para permitir que el sensor calcule el vector de gravedad en los tres ejes.</li>
  <li><b>Magnetómetro (Mag - Nivel 3):</b> Sostenemos el robot y realizamos un movimiento suave en forma de 8 en el aire para mapear el campo magnético local del entorno y filtrar posibles distorsiones.</li>
</ul>

<p><b>Lectura y Almacenamiento de Offsets en Flash/EEPROM:</b></p>

<p>
  Una vez que la función <code>getCalibration(&sys, &gyro, &accel, &mag)</code> confirma un estado global de 3, leemos la estructura de calibración <code>adafruit_bno055_offsets_t</code> mediante <code>getSensorOffsets()</code> y la guardamos directamente en la memoria no volátil del ESP32.
</p>

<p>
  Al encender el robot en la línea de salida durante la competencia, ejecutamos <code>setSensorOffsets()</code> al inicio del <code>setup()</code> para inyectar estos parámetros. Esto elimina por completo la necesidad de repetir la rutina de calibración física en la pista, reduciendo el tiempo de preparación a milisegundos.
</p>

<p><b>Gestión Avanzada en el Desafío Cerrado:</b></p> 

<p>Dada la exigencia de navegación en la WRO, implementamos una gestión optimizada de datos inerciales con el BNO055:</p> 

<ul> 

  <li><b>Persistencia de Offsets en Memoria:</b> La librería nos permite extraer la estructura de datos `adafruit_bno055_offsets_t` e inyectarla al reiniciar. El robot inicia operativo en milisegundos sin requerir rutinas de movimiento previas.</li> 

  <li><b>Compensación Dinámica:</b> Validamos la integridad de las lecturas mediante la verificación de estado (`getSystemStatus`), asegurando que si ocurre una desconexión o caída de voltaje, el código ejecute un restablecimiento controlled del bus I2C.</li> 

  <li><b>Dead-Band Control:</b> Mantenemos una "banda muerta" de sensibilidad para evitar que ligeras vibraciones del chasis transmitidas al sensor generen oscilaciones o correcciones innecesarias en el servo de dirección.</li> 

</ul> 

<p><b>Pines y Conexiones (I2C):</b></p> 

<table width="100%" style="border: 1px solid #444; border-collapse: collapse;"> 
  <thead style="background-color: rgba(255, 255, 255, 0.1);"> 
    <tr> 
      <th style="padding: 10px; border: 1px solid #444;">Pin BNO055</th> 
      <th style="padding: 10px; border: 1px solid #444;">Pin ESP32</th> 
      <th style="padding: 10px; border: 1px solid #444;">Descripción</th> 
    </tr> 
  </thead> 
  <tbody> 
    <tr> 
      <td style="padding: 10px; border: 1px solid #444; text-align: center;"><b>Vin / VCC</b></td> 
      <td style="padding: 10px; border: 1px solid #444; text-align: center;">3.3V / 5V</td> 
      <td style="padding: 10px; border: 1px solid #444;">Alimentación del módulo (regulada internamente).</td> 
    </tr> 
    <tr> 
      <td style="padding: 10px; border: 1px solid #444; text-align: center;"><b>GND</b></td> 
      <td style="padding: 10px; border: 1px solid #444; text-align: center;">GND</td> 
      <td style="padding: 10px; border: 1px solid #444;">Tierra común del sistema.</td> 
    </tr> 
    <tr> 
      <td style="padding: 10px; border: 1px solid #444; text-align: center;"><b>SCL</b></td> 
      <td style="padding: 10px; border: 1px solid #444; text-align: center;">GPIO 22</td> 
      <td style="padding: 10px; border: 1px solid #444;">Línea de reloj del bus I2C.</td> 
    </tr> 
    <tr> 
      <td style="padding: 10px; border: 1px solid #444; text-align: center;"><b>SDA</b></td> 
      <td style="padding: 10px; border: 1px solid #444; text-align: center;">GPIO 21</td> 
      <td style="padding: 10px; border: 1px solid #444;">Línea de datos del bus I2C.</td> 
    </tr> 
  </tbody> 
</table>

<p align="right">
  <a href="#inicio">Volver Al Inicio</a>
</p>

<br>
<hr>

### 3.1.6 **HuskyLens 2**

<table style="border: 1px solid #444; border-collapse: collapse; width: 100%;">
  <tr style="background-color: rgba(255, 255, 255, 0.05);">
    <td width="350px" align="center" style="padding: 20px; border: 1px solid #444;">
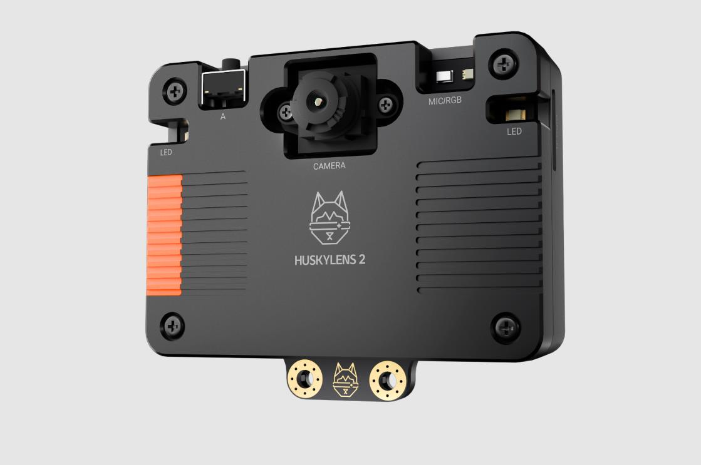
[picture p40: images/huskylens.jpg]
DFRobot HuskyLens 2
      
    </td>
    <td style="padding: 20px; border: 1px solid #444; vertical-align: top;">
      <h4 style="margin-top: 0;">⚡ Especificaciones</h4>
      <ul>
        <li><b>Librería utilizada:</b> DFRobot_HuskylensV2.h</li>
        <li><b>Procesador AI:</b> Kendryte K210 (Dual-Core RISC-V 64-bit).</li>
        <li><b>Sensor y Pantalla:</b> OV2640 (2.0 Megapíxeles) con pantalla IPS de 2.0" (320x240).</li>
        <li><b>Consumo de corriente:</b> ~230 mA @ 5V (máximo con pantalla encendida).</li>
        <li><b>Interfaces:</b> UART, I2C.</li>
        <li><b>Algoritmos integrados:</b> Reconocimiento de color, seguimiento de objetos, AprilTags, reconocimiento facial.</li>
        <li><b>Tasa de baudios (UART):</b> 115200 bps (configurable).</li>
      </ul>
    </td>
  </tr>
</table>

<p style="margin-top: 15px;">
  La <b>HuskyLens 2</b> es el "ojo" inteligente de nuestro robot y constituye una cámara de visión artificial con inteligencia artificial integrada. Resulta ideal para la detección rápida y fiable de los bloques del desafío cerrado. A diferencia de las soluciones basadas en cámaras genéricas, la HuskyLens 2 procesa imágenes <b>onboard</b> gracias a su coprocesador K210, liberando al procesador principal (ESP32) de tareas intensivas y permitiendo que <b>Heimdall</b> tome decisiones en milisegundos. Además, cuenta con una pantalla integrada y un enfoque de "aprender por demostración" mediante botones físicos, lo que simplifica enormemente el entrenamiento en la pista sin necesidad de conectarla a una computadora.
</p>

> [!TIP]
> - Aprovecha la pantalla integrada en las rondas de práctica para verificar visualmente que la cámara está enmarcando correctamente los bloques antes de iniciar la carrera.
> - Si cambian de lado en la pista, utiliza el botón de aprendizaje rápido de la cámara para registrar los colores nuevamente bajo la nueva iluminación.

> [!WARNING]
> - A veces, por más de que hayas configurado bien la cámara, si no vuelves a calibrar los colores en la ronda de práctica, los reflejos o cambios drásticos en la luz del recinto pueden causar falsos negativos.

<p><b>¿Por qué reemplazamos la Pixy2 por la HuskyLens 2?</b></p>
<p>
  Inicialmente consideramos el uso de la cámara Pixy2; sin embargo, durante las pruebas operativas decidimos migrar a la <b>HuskyLens 2</b> debido a su superioridad técnica en la clasificación de colores bajo condiciones variables de luz. La HuskyLens 2 ofrece un rendimiento visual de mayor definición, algoritmos integrados basados en aprendizaje automático y un consumo de corriente significativamente menor, optimizando la autonomía energética del sistema.
</p>

| Criterio de Comparación | DFRobot HuskyLens 2 | Pixy2 Camera |
| :--- | :--- | :--- |
| **Sensor óptico y Calidad** | **OV2640 (2.0 MP HD)** | CMOS (0.3 MP - $1280 \times 800$ procesado) |
| **Precisión en Color** | **Superior (Entrenamiento con IA y filtrado de sombras)** | Media (Basado únicamente en firmas HSV estándar) |
| **Procesador Onboard** | **Kendryte K210 (Dual-Core 64-bit RISC-V con NPU)** | NXP LPC4330 (Dual-Core ARM Cortex M4/M0) |
| **Consumo de Corriente** | **~230 mA @ 5V** (Menor consumo) | ~140 mA a 400 mA (picos altos con LEDs) |
| **Funciones Adicionales** | **Reconocimiento Facial, Objetos, AprilTags, Clasificación IA** | Seguimiento de líneas y firmas de color básicas |
| **Ajuste en Competencia** | **Pantalla IPS 2.0" y aprendizaje mediante un botón** | Requiere PC y software PixyMon para calibres finos |

<p><b>¿Por qué decidimos usar esta cámara?:</b></p>

<ul>
  <li><b>Gestión de IDs con DFRobot_HuskylensV2.h:</b> Mediante la librería oficial para esta versión, accedemos a los datos de visión estructurados. En nuestro código, el <b>ID 1</b> detecta bloques verdes y el <b>ID 2</b> bloques rojos, permitiendo diferenciar la dirección de esquiva necesaria al instante.</li>
  <li><b>Filtrado por Tamaño (Umbrales):</b> Implementamos umbrales específicos evaluando las variables de ancho y alto del objeto detectado (<code>result.width</code> y <code>result.height</code>). Solo cuando el bloque ocupa el tamaño suficiente en pantalla, el robot lo considera un obstáculo cercano y no ruido de fondo, iniciando la maniobra de evasión.</li>
  <li><b>Depuración Visual Directa:</b> La pantalla IPS nos permite ver en tiempo real qué está detectando el algoritmo (con cuadros delimitadores), lo que resulta invaluable en un entorno competitivo donde el tiempo de ajuste es limitado.</li>
  <li><b>Independencia de Procesamiento:</b> El ESP32 solo recibe paquetes de datos por UART con las coordenadas (X, Y) y el ID, dedicando su potencia íntegramente al control PID de los motores y la lectura del giroscopio.</li>
</ul>

<p><b>¿Por qué UART en lugar de I2C?:</b></p>

<p>
  La decisión entre usar el protocolo <b>UART</b> o <b>I2C</b> para la HuskyLens 2 fue un paso clave en la arquitectura de hardware. Decidimos utilizar UART para mantener la cámara en un canal de comunicación punto a punto dedicado (Hardware Serial), asegurando una transferencia constante de <i>frames</i> de datos y dejando el bus I2C del ESP32 completamente libre y exclusivo para la lectura de alta velocidad del giroscopio BNO055.
</p>

<table width="100%" style="border: 1px solid #444; border-collapse: collapse; margin: 20px 0;">
  <thead>
    <tr style="background-color: rgba(88, 166, 255, 0.1);">
      <th style="padding: 10px; border: 1px solid #444; text-align: left;">Parámetro</th>
      <th style="padding: 10px; border: 1px solid #444; text-align: left;">Protocolo UART</th>
      <th style="padding: 10px; border: 1px solid #444; text-align: left;">Protocolo I2C</th>
    </tr>
  </thead>
  <tbody>
    <tr>
      <td style="padding: 10px; border: 1px solid #444;"><b>Topología</b></td>
      <td style="padding: 10px; border: 1px solid #444;"><b>Punto a punto</b> (Dedicado)</td>
      <td style="padding: 10px; border: 1px solid #444;">Bus compartido (Múltiples esclavos)</td>
    </tr>
    <tr>
      <td style="padding: 10px; border: 1px solid #444;"><b>Tipo de Enlace</b></td>
      <td style="padding: 10px; border: 1px solid #444;">Full-Duplex (RX y TX simultáneos)</td>
      <td style="padding: 10px; border: 1px solid #444;">Half-Duplex</td>
    </tr>
    <tr>
      <td style="padding: 10px; border: 1px solid #444;"><b>Gestión de Hardware</b></td>
      <td style="padding: 10px; border: 1px solid #444;">Previene cuellos de botella con otros sensores</td>
      <td style="padding: 10px; border: 1px solid #444;">Puede retrasar lecturas del giroscopio</td>
    </tr>
  </tbody>
</table>

> [!WARNING]
> ☑️ **Elige UART si:** Necesitas un canal dedicado que no interfiera con otros sensores críticos de la pista (como el BNO055).
> 
> ☑️ **Elige UART si:** Quieres aprovechar los puertos Hardware Serial adicionales (Serial2) del ESP32 para una lectura ininterrumpida.

<p><b>Otras razones por las cuales el protocolo UART nos resultó favorable en Heimdall:</b></p>
<ul>
  <li><b>Independencia de Buses:</b> Si un sensor en el bus I2C falla o se desconecta por vibraciones, la cámara seguirá transmitiendo por UART sin colgar el sistema.</li>
  <li><b>Buffer de Hardware:</b> El ESP32 maneja el buffer UART eficientemente en segundo plano, evitando la pérdida de paquetes de datos de la cámara.</li>
  <li><b>Simplicidad de Cableado:</b> Solo requiere cruzar TX y RX, sin necesidad de calcular resistencias <i>pull-up</i> adicionales en placas perforadas.</li>
</ul>

<p><b>Lógica de Posicionamiento:</b></p>
<p>
  Dividimos el campo visual (resolución de 320x240) en tres sectores (Izquierda, Centro, Derecha) comparando la coordenada <code>result.xCenter</code> del bloque con un umbral central (aprox. <code>160</code>). Esto permite que el robot sepa no solo qué color ve (ID), sino exactamente dónde está el obstáculo en su campo visual para decidir si debe realizar una <b>esquiva preventiva suave</b> o una <b>maniobra de evasión completa</b>.
</p>

<p><b>Conexión de Pines (Hardware Serial 2):</b></p>

<table width="100%" style="border: 1px solid #444; border-collapse: collapse;">
  <thead style="background-color: rgba(255, 255, 255, 0.1);">
    <tr>
      <th style="padding: 10px; border: 1px solid #444;">Pin HuskyLens 2</th>
      <th style="padding: 10px; border: 1px solid #444;">Pin ESP32 (UART2)</th>
      <th style="padding: 10px; border: 1px solid #444;">Función</th>
    </tr>
  </thead>
  <tbody>
    <tr>
      <td style="padding: 10px; border: 1px solid #444; text-align: center;"><b>TX (Transmisión)</b></td>
      <td style="padding: 10px; border: 1px solid #444; text-align: center;">GPIO 16 (RX2)</td>
      <td style="padding: 10px; border: 1px solid #444;">Envía los datos de los bloques detectados al ESP32.</td>
    </tr>
    <tr>
      <td style="padding: 10px; border: 1px solid #444; text-align: center;"><b>RX (Recepción)</b></td>
      <td style="padding: 10px; border: 1px solid #444; text-align: center;">GPIO 17 (TX2)</td>
      <td style="padding: 10px; border: 1px solid #444;">Recibe peticiones de lectura desde el ESP32.</td>
    </tr>
    <tr>
      <td style="padding: 10px; border: 1px solid #444; text-align: center;"><b>5V / VCC</b></td>
      <td style="padding: 10px; border: 1px solid #444; text-align: center;">VIN / 5V</td>
      <td style="padding: 10px; border: 1px solid #444;">Alimentación principal de la cámara.</td>
    </tr>
    <tr>
      <td style="padding: 10px; border: 1px solid #444; text-align: center;"><b>GND</b></td>
      <td style="padding: 10px; border: 1px solid #444; text-align: center;">GND</td>
      <td style="padding: 10px; border: 1px solid #444;">Referencia común de tierra.</td>
    </tr>
  </tbody>
</table>

<p align="right">
  <a href="#inicio">Volver Al Inicio</a>
</p>

<br>
<hr>

###  Configuración para Entrenamiento de Detección de Colores
  
  <tr style="background-color: rgba(255, 255, 255, 0.05);">
    <td align="left" style="padding: 20px; border: 1px solid #444;">
    <p><i>Interfaz de la Huskylens durante el entrenamiento de deteccion de color.</i></p>
      Entrenamiento en Huskylens
    </td>
  </tr>

<br>
<table style="width: 100%; border-collapse: collapse; border: 1px solid #30363d;">
  <!-- FILA SUPERIOR: SECCIONES 1 Y 3 -->
  <tr>
    <td valign="top" style="width: 50%; padding: 15px; border-bottom: 1px solid #30363d; border-right: 1px solid #30363d;">
      <h4 style="margin-top: 0; color: #58a6ff;">1. Inicio y Encuadre Inicial</h4>
      <ul>
        <li><b>Selección de Algoritmo:</b> Deslizar en la pantalla táctil de la HuskyLens 2 hasta posicionar la interfaz en la función <b>Color Recognition</b>.</li>
        <li><b>Enfoque por Marcador Central:</b> Apuntar la cámara de modo que la cruz blanca central (<b>+</b>) coincida exactamente sobre la superficie o bloque a reconocer.</li>
        <li><b>Pre-detección Dinámica:</b> Observar el recuadro blanco que la cámara genera automáticamente alrededor del tono delimitado por la cruz central.</li>
      </ul>
    </td>
    <td valign="top" style="width: 50%; padding: 15px; border-bottom: 1px solid #30363d;">
      <h4 style="margin-top: 0; color: #58a6ff;">3. Calibración y Filtrado de Pista</h4>
      <ul>
        <li><b>Tolerancia de Color (Detection Threshold):</b> Ajustar la barra deslizante según las condiciones de iluminación. Un valor más alto incrementa la exigencia de pureza de color, reduciendo falsos positivos causados por sombras o reflejos.</li>
        <li><b>Filtrado de Área (Color Block Area Threshold):</b> Aumentar el umbral de superficie mínima en píxeles para ignorar destellos lejanos, sombras de la pista o ruido visual de menor tamaño que el objeto objetivo.</li>
      </ul>
    </td>
  </tr>
  <!-- FILA INFERIOR: SECCIONES 2 Y 4 -->
  <tr>
    <td valign="top" style="width: 50%; padding: 15px; border-right: 1px solid #30363d;">
      <h4 style="margin-top: 0; color: #58a6ff;">2. Captura y Clasificación de Firmas</h4>
      <ul>
        <li><b>Aprendizaje de Primera Firma (ID1):</b> Posicionar el marcador sobre el objetivo y presionar el <b>Botón A</b> (esquina superior derecha). El recuadro cambiará a un color sólido con la etiqueta <code>Color: ID1</code>.</li>
        <li><b>Entrenamiento Multicolor (ID2, ID3...):</b> Apuntar la cruz hacia un nuevo bloque de color y presionar nuevamente el <b>Botón A</b> para registrar identificadores adicionales de forma secuencial.</li>
        <li><b>Asignación de Nombres (Set Name):</b> Acceder al parámetro <i>Set Name</i>, elegir el ID correspondiente y utilizar el teclado en pantalla para guardar nombres personalizados (ej: <i>VERDE</i>, <i>ROJO</i>, <i>MAGENTA</i>).</li>
      </ul>
    </td>
    <td valign="top" style="width: 50%; padding: 15px;">
      <h4 style="margin-top: 0; color: #58a6ff;">4. Mantenimiento y Memoria No Volátil</h4>
      <ul>
        <li><b>Resguardo de Modelos (Export Model):</b> Seleccionar la opción <i>Export Model</i> para almacenar el entrenamiento en un slot de memoria interna (Slot 0 al 4). Esto genera los archivos <code>.json</code> y <code>.bin</code> para no perder las firmas al reiniciar el dispositivo.</li>
        <li><b>Depuración de Firmas (Forget ID / Reset):</b> Utilizar <i>Forget ID</i> y apuntar hacia un objeto para eliminar una firma específica, o seleccionar <i>Restore Defaults</i> si se requiere reiniciar la configuración general a valores de fábrica.</li>
      </ul>
    </td>
  </tr>
</table>

<p align="right">
  <a href="#inicio">Volver Al Inicio</a>
</p>

<br>
<hr>

## 3.2 Microcontrolador

### 3.2.1 **ESP32-WROOM-32**

<table style="border: 1px solid #444; border-collapse: collapse; width: 100%;">
  <tr style="background-color: rgba(255, 255, 255, 0.05);">
    <td width="350px" align="center" style="padding: 20px; border: 1px solid #444;">
      ESP32-WROOM-32 Module
    </td>
    <td style="padding: 20px; border: 1px solid #444; vertical-align: top;">
      <h4 style="margin-top: 0;">⚡ Especificaciones del Módulo</h4>
      <ul>
        <li><b>Módulo:</b> ESP32-WROOM-32 (Integrado con chip ESP32-D0WDQ6).</li>
        <li><b>CPU:</b> Dual-core Xtensa® 32-bit LX6 (hasta 240 MHz).</li>
        <li><b>ROM/SRAM:</b> 448 KB ROM / 520 KB SRAM.</li>
        <li><b>Flash Externa:</b> 4 MB integrados en el módulo.</li>
        <li><b>Cristal Oscilador:</b> 40 MHz integrado.</li>
        <li><b>Seguridad:</b> Aceleradores de hardware para AES, SHA-2, RSA y ECC.</li>
        <li><b>Temperatura de operación:</b> -40°C a +85°C (Ideal para competencia).</li>
      </ul>
    </td>
  </tr>
</table>

<p style="margin-top: 15px;">
  El <b>ESP32-WROOM-32</b> es un potente módulo MCU todo-en-uno que actúa como el cerebro central de <b>Heimdall</b>. Elegimos esta plataforma principalmente por su elevada velocidad de procesamiento (240 MHz) y su arquitectura de doble núcleo, que permite gestionar procesos multihilo: mientras un núcleo se encarga de la lógica de visión artificial, el otro procesa la lectura de sensores ultrasónicos y el control PID en tiempo real. Su versatilidad lo hace ideal para robótica móvil, permitiendo una programación eficiente mediante Arduino IDE.
</p>

<p><b>¿Por qué elegimos el ESP32 sobre otros microcontroladores?</b></p>
<p>
  Frente a alternativas tradicionales como el Arduino Mega o el Raspberry Pi Pico, el ESP32 ofrece la mayor frecuencia de reloj (240 MHz) y una arquitectura nativa de doble núcleo a un bajo consumo energético. Esta velocidad de cómputo superior es fundamental para ejecutar la FSM y los algoritmos PID sin retrasos de procesamiento al recibir paquetes pesados por UART desde la HuskyLens 2.
</p>

| Criterio | ESP32-WROOM-32 | Arduino Mega 2560 | Raspberry Pi Pico (RP2040) |
| :--- | :--- | :--- | :--- |
| **Frecuencia de CPU** | **240 MHz (Dual-Core)** | 16 MHz (Single-Core) | 133 MHz (Dual-Core) |
| **Memoria SRAM** | **520 KB** | 8 KB | 264 KB |
| **Memoria Flash** | **4 MB** | 256 KB | 2 MB |
| **Arquitectura** | **32-bit Xtensa LX6** | 8-bit AVR | 32-bit ARM Cortex-M0+ |
| **Multihilo Nativo** | **Sí (FreeRTOS / 2 Cores)** | No | Limitado |
| **Rendimiento PID / Visión** | **Excelente (Sin latencia)** | Deficiente (Cuello de botella) | Aceptable |

<p><b>Ventajas para nuestro robot Heimdall:</b></p>

<ul>
  <li><b>Arquitectura Dual-Core:</b> Aprovechamos el procesamiento en paralelo para que el control PID del <code>BNO055</code> no se vea interrumpido por la lectura y el procesamiento de visión de la <code>HuskyLens 2</code>.</li>
  <li><b>Gestión de Comunicaciones (UART/I2C):</b> El WROOM-32 expone eficientemente sus periféricos de hardware, permitiendo que la cámara <b>HuskyLens 2</b> y el giroscopio <b>BNO055</b> se comuniquen con el microcontrolador mediante transferencias de datos totalmente independientes y sin cuellos de botella.</li>
  <li><b>Versatilidad PWM (LEDC):</b> La precisión del hardware nos permite controlar el servomotor en el <code>GPIO 2</code> con una resolución de 13 bits, garantizando giros suaves en las curvas del desafío.</li>
</ul>

<p><b>Librerías Esenciales:</b></p>
<p>
  Para que el hardware opere a su máximo potencial, hemos establecido un ecosistema de software basado en librerías específicas que optimizan la comunicación y el control:
</p>

<ul>
  <li><b>Wire.h (Comunicación I²C):</b> Fundamental para establecer el bus de datos con el giroscopio MPU6050. Permite configurar los pines SDA/SCL y gestionar el intercambio de datos mediante el protocolo I²C.</li>
  <li><b>NewPing:</b> Optimiza el uso de los 3 sensores ultrasónicos HC-SR04. Maneja automáticamente los pulsos y reduce errores de eco, permitiendo que el robot evite obstáculos y mantenga la distancia con las paredes de forma precisa.</li>
  <li><b>ESP32Servo.h:</b> Crucial para el manejo del servomotor de dirección. Esta librería adapta los timers PWM específicos del ESP32 para lograr un movimiento angular exacto (0°-180°) en el eje delantero.</li>
  <li><b>DFRobot_HuskylensV2.h:</b> Esencial para la comunicación con la cámara de visión artificial HuskyLens. Permite recibir rápidamente los datos visuales ya procesados por su IA, facilitando la detección de bloques y zonas de estacionamiento sin sobrecargar al ESP32.</li>
  <li><b>Adafruit_BNO055.h / imumaths.h:</b> Fundamentales para el sensor BNO055. Procesan la orientación absoluta y cálculos complejos internamente, entregando un rumbo exacto para asegurar una navegación estable sin requerir filtros manuales.</li>
</ul>

> [!WARNING]
> ☑️ **Niveles Lógicos:** El módulo opera strictly a 3.3V. Todos los periféricos de 5V integrados en Heimdall pasan por una etapa de acondicionamiento de señal para proteger las entradas del WROOM-32.

<p align="right">
  <a href="#inicio">Volver Al Inicio</a>
</p>

<br>
<hr>

## 3.3 Diagrama de Conexiones

Diagrama de Conexiones

El esquema eléctrico anterior ilustra la topología completa de interconexión entre la unidad central de procesamiento (ESP32-WROOM-32), los subsistemas de regulación de energía, la etapa de potencia y la interfaz sensórica del robot Heimdall. Se destaca la distribución independiente de las líneas de alimentación para evitar caídas de tensión lógicas (*brownouts*), la unificación de la referencia de masa (*Star Ground*) para mitigar el ruido electromagnético (EMI) y la asignación estratégica de los pines de E/S evitando el uso de *strapping pins* críticos durante el arranque del microcontrolador

<p align="right">
  <a href="#inicio">Volver Al Inicio</a>
</p>

---
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

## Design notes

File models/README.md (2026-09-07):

<div align="center">

# Modelos del Robot – Directorio `models`




*Directorio oficial con archivos de diseño, modelos CAD y componentes mecánicos listos para fabricación e impresión 3D.*

</div>

---

## Estructura del Directorio

<table width="100%">
  <tr>
    <td width="35%"><b>Subcarpeta</b></td>
    <td width="65%"><b>Propósito y Contenido</b></td>
  </tr>
  <tr>
    <td><b><a href="./Bases%20y%20Acoples%20de%20Sensores%20y%20Camara/">/Bases y Acoples de Sensores y Camara/</a></b></td>
    <td>Modelos 3D de bases, soportes y acoples para la fijación exacta de la HuskyLens 2 y el arreglo de sensores ultrasónicos.</td>
  </tr>
  <tr>
    <td><b><a href="./Heimdall%20Version%20Final/">/Heimdall Version Final/</a></b></td>
    <td>Ensamblaje maestro del prototipo completo. Incluye el archivo de intercambio en formato <code>.STEP</code> con el diseño definitivo del robot para inspección o modificación CAD integral.</td>
  </tr>
  <tr>
    <td><b><a href="./Impresion%20yDiseños%203D/">/Impresion yDiseños 3D/</a></b></td>
    <td>Archivos fuente (<code>.STL</code>, <code>.STEP</code>), guías de fabricación, parámetros de impresión, materiales recomendados y configuraciones de slicing.</td>
  </tr>
  <tr>
    <td><b><a href="./Sistema%20de%20Direccion/">/Sistema de Direccion/</a></b></td>
    <td>Componentes del tren delantero, manguetas, eslabones y piezas del sistema de dirección Ackermann diseñadas para el servomotor INJORA.</td>
  </tr>
  <tr>
    <td><b><a href="./Sistema%20de%20Transmision/">/Sistema de Transmision/</a></b></td>
    <td>Diseños de la tracción trasera: soportes del motor Hytech GA37-520, acoples de eje, engranajes y fijaciones del tren motriz.</td>
  </tr>
</table>

---

> [!NOTE]
> ### Guía de Uso de los Modelos
> 1. **Consultar la documentación específica:** Revisa el archivo README de cada subcarpeta para verificar tolerancias, notas de montaje y especificaciones técnicas.
> 2. **Descarga de archivos:** Obtén los archivos en formato <code>.STL</code> para laminación directa o utiliza el archivo <code>.STEP</code> alojado en <code>/Heimdall_final/</code> si requieres la geometría completa del ensamble en tu software CAD.
> 3. **Parámetros de impresión:** Aplica las recomendaciones de porcentaje de relleno (*infill*) y orientación de pieza para garantizar la resistencia mecánica del chasis.

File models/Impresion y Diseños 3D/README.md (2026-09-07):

### Fabricación e Impresión 3D

Una vez concluida la etapa de diseño, el proceso de fabricación se centró en la impresión 3D. La totalidad de los componentes fue fabricada en filamento **PETG-CF de la marca Sunlu**, utilizando una impresora **Qidi Q2**.

---

### Selección de Materiales y Recomendaciones

Se desaconseja categóricamente el uso de **PLA** para este proyecto debido a las elevadas temperaturas operativas y al severo estrés mecánico al que están sujetas diversas secciones del robot. 

Se seleccionó **PETG-CF** por su elevada estabilidad estructural, resistencia al impacto y alta fiabilidad en mecanismos bajo carga. Como alternativas viables, se recomienda el uso de polímeros como **PA12-CF, PETG, ABS, ASA, PC** u otros polímeros reforzados con fibra de carbono (CF).

---

### Configuración del Laminador (Slicer)

Los parámetros de impresión empleados (configurados en **QidiStudio** son los siguientes:

* **Parámetros Térmicos:** Temperatura de boquilla a 250 °C y temperatura de cama a 80 °C.
* **Resolución y Dinámica:** Altura de capa de 0,2 mm, velocidad de perímetro de 150 mm/s, velocidad de rellenado de 250 mm/s y aceleración general de 8000 mm/s².
* **Relleno y Soportes:** Patrón de rellenado triangular, con una densidad del 15 %–20 % para piezas estructurales secundarias y del 25 %–40 % para componentes bajo alto estrés mecánico. Se aplicaron soportes de tipo estándar en voladizos con pendientes superiores a 40°.

  <p align="center">
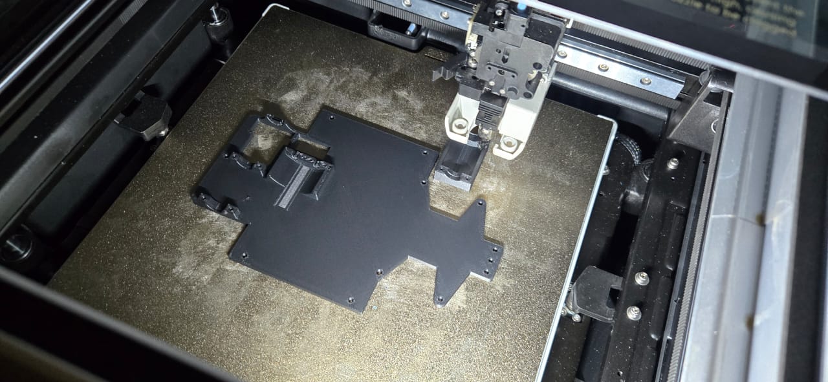
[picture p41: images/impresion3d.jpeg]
Proceso de Impresión 3D del Chasis en Qidi Q2
    <br>
  </p>

---

## Consideraciones Técnicas Generales

Estos parámetros pueden variar según el equipo y la marca del filamento utilizado. Para componentes mecánicos críticos tales como engranajes y ejes de transmisión, los cuales soportan cargas continuas y el par rotacional del motor, es indispensable emplear filamentos reforzados. 

Asimismo, se recomienda no exceder una altura de capa de 0,2 mm, ya que la precisión dimensional y la tolerancia en los acoples garantizan el ajuste milimétrico requerido durante el ensamblaje.

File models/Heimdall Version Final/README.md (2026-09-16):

### Ensamblaje Completo – Modelo 3D Definitivo (`.STL`)

En este directorio se aloja el modelo CAD tridimensional consolidado del robot. Este archivo representa la integración final de todos los subsistemas mecánicos, electrónicos y de soporte en un único volumen digital, garantizando la verificación geométrica de tolerancias, la detección de interferencias y la correcta distribución de masas antes de la fase de manufactura e impresión 3D.

---

### Características del Modelo CAD Consolidado

* **Integración Mecánica Total:**  
  Consolida en un solo entorno virtual el chasis inferior de tracción, el sistema de dirección articulada, el tren de transmisión posterior con diferencial y la superestructura superior de soporte para sensores y cámara.

* **Verificación de Tolerancias y Acoples:**  
  Diseñado respetando las holguras necesarias para rodamientos, pernos métricos, Servomotor INJORA, motor de tracción y cableado interno, reduciendo la necesidad de post-procesado manual en las piezas impresas.

* **Acceso e Inspección:**  
  Sirve como archivo maestro de consulta para laminación directa en formato `.STL` de cada componente individual o para modificación paramétrica integral a través del modelo sólido en entorno CAD.

---

### Vistas Técnicas del Ensamble Definitivo

<p align="center">
  Vista Isométrica del Ensamble Maestro Heimdall<br>
</p>

<p align="center">
  Vista Frontal del Arreglo Sensorial y Tren Delantero<br>
</p>

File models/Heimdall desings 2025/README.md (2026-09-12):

# Modelos del Robot – Carpeta `models` (Diseño 2025 - Descartado)

¡Bienvenido a la carpeta de modelos!
Aquí encontrarás todos los archivos y documentación relacionados con los componentes físicos y mecánicos del robot del año 2025, especialmente aquellos diseñados para impresión 3D.

---

> [!CAUTION]
> ### ⚠️ Estado del Proyecto: Diseño Descartado
> Los modelos contenidos en esta carpeta corresponden a la **versión 2025** y han sido **descartados para el desarrollo actual** debido a ineficiencias mecánicas y problemas de rendimiento detectados durante las pruebas en pista:
> 
> * **Juego Mecánico en Dirección:** El sistema de cruce y dirección delantera presentaba holguras/juegos excesivos, provocando imprecisión en los virajes.
> * **Desplazamiento del Servomotor:** El esfuerzo ejercido por el mecanismo de dirección hacía que el servomotor de dirección sufriera desplazamientos e inestabilidad en su soporte.
> * **Pérdida de Tracción:** El diseño del chasis y la distribución de masa ocasionaban que las ruedas patinaran constantemente, afectando la repetibilidad de la odometría por encoders.
> 
> *Este directorio se conserva exclusivamente como referencia histórica y registro de iteraciones de diseño.*

---

## Estructura de Carpetas y Descripción

A continuación se detallan las subcarpetas principales que conforman este directorio, junto a una breve descripción de su propósito:

---

### 1. **Bases y Acoples de Sensores y Cámara**
- **Descripción:**  
  Aquí se encuentran los modelos 3D de las bases y acoples para la fijación de sensores y la cámara del robot. 

---

### 2. **Cajas de Diferencial y Chasis Principal**
- **Descripción:**  
  Contiene los archivos de diseño para la estructura principal del robot, incluyendo el chasis central y las cajas del diferencial. Estos modelos brindan el soporte estructural necesario y alojan los mecanismos internos de transmisión y control.

---

### 3. **Impresión y Diseño 3D**
- **Descripción:**  
  Reúne los archivos fuente (STL, STEP, etc.) y documentación relacionada con el proceso de diseño e impresión 3D. Aquí se incluyen guías para la fabricación, recomendaciones de materiales, y configuraciones de impresión.

---

### 4. **Sistema de Movimiento Libre y Dirección Delantera**
- **Descripción:**  
  Incluye los modelos para los sistemas delanteros de dirección y movimiento libre. Aquí se encuentran los componentes que permiten al robot girar y maniobrar con precisión *(Afectado por el juego mecánico mencionado)*.

---

### 5. **Sistema de Transmisión Motriz Trasero**
- **Descripción:**  
  Contiene los diseños de la transmisión motriz trasera, tales como soportes de motores, engranajes, ejes y acoples. Estos elementos son fundamentales para el desplazamiento y la entrega de potencia a las ruedas traseras *(Afectado por patinado de ruedas)*.

---

> [!NOTE]
> ### ¿Cómo usar estos modelos?
> 1. **Revisa el README específico de cada subcarpeta** para detalles técnicos y notas de montaje de esta versión previa.
> 2. **Descarga los archivos de la pieza que necesites** si deseas analizar el histórico de diseño o reutilizar acoples secundarios.
> 3. **Consulta las guías y diagramas** para estudiar las iteraciones anteriores y evitar repetir estos fallos mecánicos en las nuevas versiones del robot.

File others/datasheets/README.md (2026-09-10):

# Datasheets – Referencias de Componentes de Hardware

Este directorio contiene las hojas de datos (*datasheets*) oficiales del fabricante y la documentación técnica de todos los componentes principales utilizados en el vehículo robótico **Heimdall**.

Estos documentos y fichas fueron consultados y utilizados durante:

* Diseño del esquema eléctrico y distribución de potencia.
* Desarrollo de firmware y controladores.
* Integración de sensores y calibración de visión.
* Control dinámico de motores y regulación de voltaje.
* Planificación de la arquitectura general del sistema.

---

## Componentes Incluidos

### Microcontrolador ESP32-WROOM-32
Unidad de procesamiento principal encargada del control en tiempo real, gestión de sensores, lógica de navegación y algoritmo de dirección.

**Archivo:**
* [](./esp32-wroom-32_datasheet_en.pdf)

---

### Módulo Regulador Step-Down
Módulo encargado de la regulación eficiente del voltaje proveniente de la batería, reduciendo y estabilizando la tensión a los niveles requeridos por la electrónica de control y sensores (5V / 3.3V).

**Archivo:**
* [](./LM2596%20SIMPLE%20SWITCHER®%20Power%20Converter%20150-kHz%203-A%20Step-Down%20Voltage%20Regulator%20datasheet%20(Rev.%20G)%20-%20lm2596.pdf)

---

### Driver de Motor / Puente H
Controlador de potencia encargado de gestionar el sentido de giro y la velocidad mediante señales PWM aplicadas al motor DC de tracción trasera.

**Archivo:**
* [](./L298N%20Motor%20Driver.pdf)

---

### Sensor IMU BNO055
Unidad de medición inercial de 9 ejes con fusión de datos integrada para la lectura precisa de orientación y aceleración.

**Archivo:**
* [](./BNO055.pdf)

---

### Sensor de Distancia Ultrasónico HC-SR04
Arreglo de sensores para la detección periférica de obstáculos y cálculo de distancias por ultrasonido.

**Archivo:**
* [](./HC-SR04%20-%20HCSR04.pdf)

---

### Cámara de Visión Artificial HuskyLens 2 (DFRobot)
Módulo de visión por IA dedicado al reconocimiento de colores, seguimiento de líneas, etiquetas y procesamiento de imágenes en tiempo real.

> [!NOTE]
> *Debido a la ausencia de un documento PDF oficial descargable por parte del fabricante, se redactó una ficha técnica detallada dentro del repositorio.*

**Documentación:**
* [](./huskylens2.md)

---

### Servomotor INJORA INJ2065 7
Servomotor digital reforzado de perfil bajo y piñonería metálica, encargado del sistema de dirección articulada.

> [!NOTE]
> *Dado que el fabricante provee especificaciones directas de catálogo en lugar de un datasheet formal, se elaboró una guía técnica de referencia.*

**Documentación:**
* [](./injora2065.md)

---

### Motor con Reductora Hytech GA37-520 (12V con Encoder)
Motor DC de tracción trasera integrado con caja reductora y encoder de efecto Hall para el control de velocidad en bucle cerrado.

> [!NOTE]
> *Se sintetizaron los parámetros mecánicos, relación de reducción y diagrama del encoder en una ficha técnica Markdown dedicada.*

**Documentación:**
* [](./hytech_ga37.md)

---

## Propósito de este Directorio

El análisis continuo de estas fichas técnicas asegura:

* **Niveles de voltaje correctos y aislamiento de potencia** para evitar daños en componentes de 3.3V / 5V / 12V.
* **Manejo térmico y de corriente adecuado** en el convertidor Step-Down y Puente H bajo cargas continuas.
* **Configuración precisa de tiempos e interrupciones** para buses de comunicación I2C, SPI y UART.
* **Ajuste fino de lectura de encoders** para el control PID del motor de tracción.

*Todas las decisiones de diseño e integración eléctrica de este proyecto se basan estrictamente en estos documentos técnicos.*

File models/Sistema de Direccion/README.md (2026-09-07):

### Sistema de Direccion

Este sistema cuenta con libertad total de las ruedas delanteras para girar e inclinarse sin la presencia de ejes de transmisión conectados, lo cual elimina por completo el arrastre mecánico y aporta una fluidez absoluta al desplazamiento del robot. Esta configuración otorga la máxima libertad posible al afrontar las curvas más cerradas de la pista, trabajando en conjunto con una geometría de dirección articulada donde los brazos de dirección se acoplan directamente a los nudillos de dirección y al servomotor central.

---

### Componentes Mecánicos del Tren Delantero

* **Brazo de Dirección:**  
  Eslabones mecánicos de alta rigidez encargados de vincular el acople de la bocina del servo con los nudillos de dirección de cada rueda. Su función principal es transmitir el movimiento angular generado por el servomotor de forma simétrica e instantánea a ambas ruedas delanteras. Este diseño de bieletas garantiza virajes estables y permite alcanzar ángulos de cruce de hasta 55° (±5°) con un juego mecánico prácticamente inexistente, permitiendo correcciones de trayectoria finas a alta velocidad.

* **Acople de Bocina:**  
  Componente maestro de distribución de par montado de forma directa sobre la boquilla metálica del servomotor INJORA. Diseñado con puntos de articulación optimizados, actúa como el puente mecánico central que divide la fuerza de rotación del servo y la convierte en un movimiento de empuje y tracción lineal hacia los brazos de dirección. Su tolerancia de encaje elimina la histeresis en el centrado de la dirección, asegurando que el robot mantenga una línea recta perfecta tras salir de una curva.

* **Nudillo de Dirección:**  
  Pieza pivotante de alta precisión encargada de albergar los rodamientos de la rueda y permitir su rotación angular respecto al eje vertical del chasis. Se encuentra fijado en sus extremos superior e inferior mediante pernos de pivote que actúan como manguetas de dirección, permitiéndole girar con total libertad para cambiar la orientación de los neumáticos según el empuje dinámico recibido desde los brazos de dirección.

  <p align="center">
    Geometría del Sistema de Dirección en CAD<br>
  </p>

---

## Anexos del Sistema Montado

El ensamble físico demuestra la integración real de la articulación de dirección, el servomotor central y las ruedas montadas sobre la estructura impresa en 3D:

<p align="center">
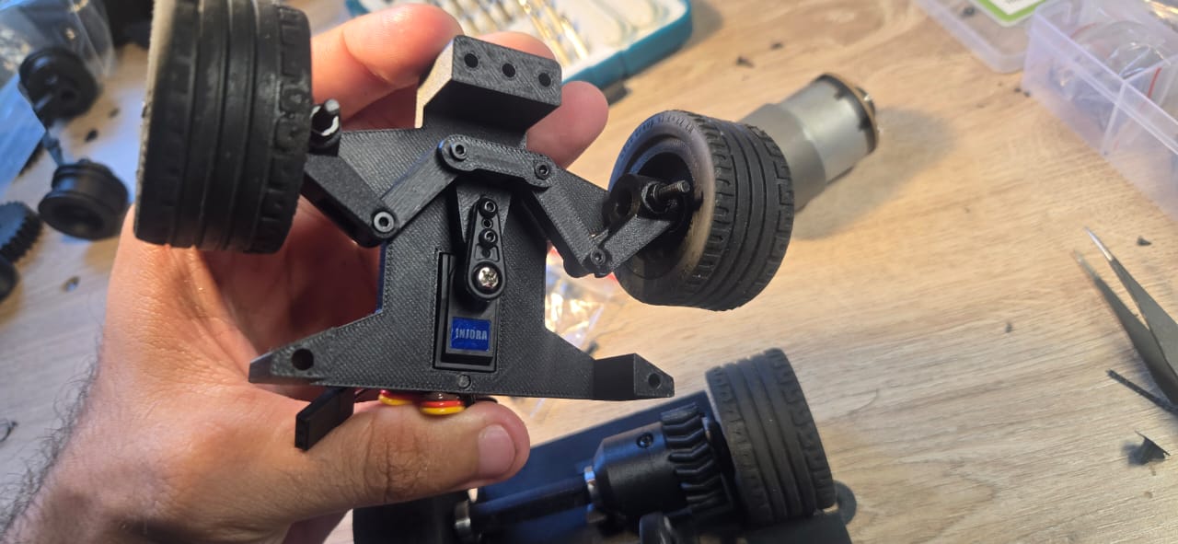
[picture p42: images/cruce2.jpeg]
Ensamble Físico del Tren Delantero
  <br>
</p>

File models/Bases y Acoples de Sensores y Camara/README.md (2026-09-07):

### Base de Sensores y Soporte de Cámara

En este apartado se detalla el conjunto modular de soportes y estructuras encargadas de albergar los componentes de percepción sensorial del robot. Dado que la toma de decisiones en tiempo real depende directamente de la precisión y estabilidad de los datos recolectados, estas piezas fueron diseñadas con una rigidez estructural absoluta, mitigando cualquier tipo de vibración mecánica derivada de la tracción y garantizando que el campo de visión y los haces de ultrasonido se mantengan perfectamente alineados durante todo el recorrido en pista.

La estructura completa se compone de tres módulos biomecánicos optimizados, impresos en 3D y estructurados para ofrecer ligereza, resistencia e intervención rápida en situaciones críticas de boxes:

* **Base Principal de Ultrasónicos:**  
  Constituye la plataforma central de la arquitectura sensorial. Diseñada para posarse y atornillarse directamente sobre la parte superior del chasis, esta base asegura un centro de gravedad bajo y una fijación inamovible al chasis principal. Dispone de tres bahías de acople orientadas espacialmente hacia el frente, flanco izquierdo y flanco derecho, cubriendo el perímetro de navegación sin generar zonas ciegas. Su geometría incluye rutas internas para la canalización organizada del cableado y de alimentación, evitando interferencias con las partes móviles de la dirección.

  <p align="center">
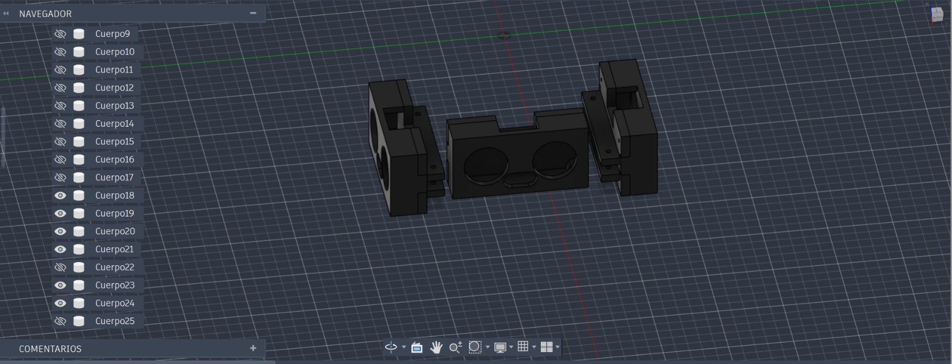
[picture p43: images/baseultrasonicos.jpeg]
Base Principal de Ultrasónicos
    <br>
  </p>

---

* **Acoples Modulares para Sensores Ultrasónicos:**  
  Diseñados como carcasas de protección y fijación para los transductores de distancia. Estas piezas se acoplan mecánicamente a las bahías de la base principal mediante un ajuste de tolerancia preciso que permite montar y desmontar los sensores ultrasónicos de manera sencilla y rápida. Esta modularidad resulta vital en entornos de competencia, ya que permite reemplazar una unidad dañada o ajustar su orientación en cuestión de segundos sin necesidad de desarmar la estructura del chasis.

  <p align="center">
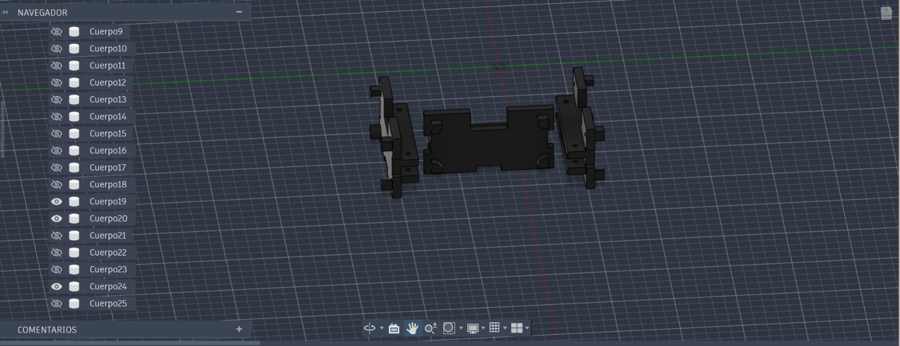
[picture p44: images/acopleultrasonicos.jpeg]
Acoples Modulares para Sensores Ultrasónicos
    <br>
  </p>

---

* **Soporte Elevado de Cámara (HuskyLens 2):**  
  Estructura vertical reforzada que se erige desde el centro de la base principal para otorgar la elevación y el ángulo de inclinación óptimos al módulo de visión artificial. Su diseño en torre eleva la lente por encima del tren delantero, asegurando un campo de visión despejado para el reconocimiento de colores, bloques y marcas de pista. Adicionalmente, cuenta con una arquitectura de perfil abierto que favorece la convección natural del aire, garantizando una refrigeración pasiva constante para el procesador de la cámara durante secuencias largas de procesamiento de imagen.

  <p align="center">
    Soporte Elevado de Cámara<br>
  </p>

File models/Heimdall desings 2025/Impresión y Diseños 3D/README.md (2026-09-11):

Ya habiendo pasado el apartado de diseño, ahora enfocandonos en el apartado de impresión 3D; Todas las piezas fueron impresas en PETG de la marca Sunlu con una impresora Creality Ender 3v3 Ke.
Como recomendaciones para impresión recomendamos no utilizar Pla para este proyecto ya que tendrá que soportar altas temperaturas y un estrés mecánico alto en algunas partes del robot, utilizamos PETG gracias a su estabilidad estructural y resistencia a impactos y su alta fiabilidad en mecanismos y piezas que requieran cualquier tipo de estrés, con ello también recomendamos utilizar Nylon-6/PETG-CF/ABS/ASA/PC y muchos otros filamentos reforzados con fibra de carbono (CF)
Ya en configuraciones de impresión nos encontramos con:
Altura de capa:0.2mm
Temperatura de boquilla:250°C
Temperatura de Cama:95°C
Velocidad de perímetro: 250mm/s
Velocidad de relleno: 400mm/s
Aceleración general: 5000mm/s²
Densidad: 30-50% piezas sin estrés mecánico 60-100% piezas con alto estrés mecánico 
Soportes: Utilizamos en todas las piezas soportes normales en todas las piezas con pendientes de más de 50°
Patrón de relleno: triangular
Dependiendo de la impresora y filamento empleado para el proyecto todas las configuraciones podrían variar, se recomienda utilizar filamentos reforzados para piezas mecánicas como los palieres y juntas las cuales son las que llevan la mayoría del estrés de la fuerza de rotación del motor de manera continua, en conjunto con eso recomendamos no usar una altura de capa mayor a 0.2mm por los acabados de los palieres y algunas bases que es fundamental debido a las tolerancias de las mismas; también probar en su laminador de preferencia (en nuestro caso utilizamos Orca Sliced) las tolerancias de las piezas para no tener problemas con las mismas

Imagen de WhatsApp 2025-06-14 a las 05 27 22_e1aa1fb6

Imagen de WhatsApp 2025-06-14 a las 05 27 22_a25a2e54

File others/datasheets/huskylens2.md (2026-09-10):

# Ficha Técnica / Datasheet – DFRobot HuskyLens 2 (Módulo de Visión por IA)

## 1. Descripción General
La **HuskyLens 2** es una cámara de visión artificial autónoma y acelerada por hardware orientada a procesamiento *Edge AI*. Integra un procesador de redes neuronales (KPU) que ejecuta algoritmos de visión por computador directamente en el dispositivo, transmitiendo únicamente resultados procesados (coordenadas, áreas, identificadores) al microcontrolador anfitrión mediante interfaces de comunicación seriales o de bus.

---

## 2. Principio de Funcionamiento y Procesamiento Optoelectrónico

### 2.1 Captura y Mapeo Óptico
El sensor de imagen CMOS convierte la luz enfocada por la lente en señales digitales de píxeles, entregando un flujo de video interno al procesador principal.

### 2.2 Aceleración por Hardware (KPU)
A diferencia de los sistemas basados en software convencional, la HuskyLens 2 utiliza una **Unidad de Procesamiento KPU** (acelerador matricial). La KPU ejecuta capas convolucionales de redes neuronales en paralelo sobre el búfer del frame de entrada, extrayendo características espaciales y vectores geométricos sin requerir procesamiento por parte de un microcontrolador externo.

### 2.3 Protocolo de Salida Asíncrono
Una vez que el algoritmo en ejecución procesa el fotograma, emite un paquete estructurado de datos (en formato binario o texto delimitado) por la interfaz UART o I2C conteniendo la información de los objetos detectados (*Bounding Boxes*, centroides o vectores).

---

## 3. Especificaciones Técnicas Principales

| Parámetro | Valor / Rango | Unidad |
| :--- | :--- | :--- |
| **Procesador Principal** | Kendryte K210 (Dual-Core RISC-V 64-bit @ 400 MHz) | - |
| **Acelerador de IA** | KPU integrador de convolución matricial | - |
| **Sensor de Imagen** | OV2640 (2.0 Megapíxeles) | - |
| **Pantalla Integrada** | IPS de 2.0 pulgadas | px |
| **Resolución de Pantalla** | 320 x 240 | - |
| **Voltaje de Alimentación (VCC)** | 3.3 – 5.0 | V DC |
| **Consumo de Corriente (Operativo)** | 320 – 420 | mA |
| **Temperatura de Operación** | -10 a +60 | °C |
| **Nivel Lógico I/O** | 3.3 (Tolerante a 5V en líneas de comunicación) | V |
| **Dimensiones Físicas** | 52.0 x 44.5 x 19.0 | mm |

---

## 4. Algoritmos Integrados y Teoría Operativa

### 4.1 Clasificación y Reconocimiento de Objetos (Object Recognition)
* **Principio:** Utiliza una red neuronal convolucional (CNN) entrenada para detectar la presencia de clases de objetos específicas dentro del marco óptico.
* **Datos de Salida:**
  * Coordenadas de marco delimitador: $X_{min}$, $Y_{min}$, $X_{max}$, $Y_{max}$ (en píxeles).
  * ID asignado a la clase detectada.
  * Porcentaje de probabilidad/confianza de la detección.

### 4.2 Tracking y Vectorización de Líneas (Line Tracking)
* **Principio:** Evalúa diferencias de contraste y gradientes cromáticos para aislar patrones continuos y estimar la trayectoria de un carril o línea.
* **Datos de Salida:**
  * Punto inicial del vector: $(X_1, Y_1)$.
  * Punto final del vector: $(X_2, Y_2)$.
  * Ángulo de inclinación del vector ($\theta$) respecto a la vertical del marco.

### 4.3 Discriminación de Color (Color Recognition)
* **Principio:** Transforma el espacio de color RGB de la imagen al espacio de color HSV/LAB, permitiendo filtrar variaciones de iluminancia y aislar rangos de matiz (*hue*) y saturación (*saturation*).
* **Datos de Salida:**
  * Coordenadas del centroide del objeto de color: $(X_{c}, Y_{c})$.
  * Área del bloque de color (píxeles totales acumulados).
  * ID numérico asignado a la paleta de color aprendida.

### 4.4 Detección de Marcadores Fiduciales y AprilTags
* **Principio:** Realiza un proceso de umbralización adaptativa (*adaptive thresholding*) y análisis de cuadrantes binarios para descodificar la matriz de información de la etiqueta.
* **Datos de Salida:**
  * Identificador numérico único encodificado en la matriz.
  * Centroide $2D$ del marcador en pantalla.
  * Estimación de la matriz de pose $3D$ (rotaciones en yaw, pitch y roll respecto al plano focal).

### 4.5 Reconocimiento Facial (Face Recognition)
* **Principio:** Extrae un mapa de rasgos faciales (*facial landmarks*) combinando localización de puntos clave (ojos, nariz, comisura labial) y extracción de incrustaciones (*embeddings*).
* **Datos de Salida:**
  * Bounding box del rostro detectado.
  * ID de coincidencia almacenado en la memoria de usuario.

---

## 5. Descripción de Interfaces y Pinout

El puerto de conexión físico de 4 pines soporta multiplexación interna para UART e I2C.

| Pin N° | Etiqueta | Tipo | Función en Modo UART | Función en Modo I2C |
| :---: | :--- | :--- | :--- | :--- |
| **1** | VCC | Alimentación | 3.3V - 5V DC entrada de potencia | 3.3V - 5V DC entrada de potencia |
| **2** | GND | Tierra | Tierra común de referencia | Tierra común de referencia |
| **3** | TX / SDA | Salida / I/O | Transmisión de datos Serie (3.3V) | Línea de Datos I2C (SDA) |
| **4** | RX / SCL | Entrada | Recepción de datos Serie (3.3V) | Línea de Reloj I2C (SCL) |

### Parámetros de Comunicación
* **UART por Defecto:** Baudrate 9600 bps, 8 bits de datos, sin paridad, 1 bit de parada (9600 8N1). Configurable hasta 115200 bps.
* **I2C por Defecto:** Dirección esclava de bus `0x32`.

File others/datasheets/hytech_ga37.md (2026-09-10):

# Ficha Técnica / Datasheet – Motor DC Hytech GA37-520 con Encoder Magnético de Cuadratura

## 1. Descripción General
El **Hytech GA37-520** es un sistema electromecánico integrado compuesto por un motor de corriente continua, una caja de engranajes reductora de perfil cilíndrico (37 mm) y un encoder incremental magnético de efecto Hall montado sobre el eje posterior del rotor. Proporciona alto par rotacional y capacidad de monitoreo de velocidad/posición en bucle cerrado.

---

## 2. Principios Físicos de Funcionamiento

### 2.1 Conversión Electromecánica (Motor DC)
El motor opera bajo el principio de la fuerza de Lorentz ($F = I \cdot L \times B$). Cuando la corriente fluye a través de las escobillas hacia el colector y los devanados del inducido, la interacción con el campo magnético del estator permanente genera un par de torsión que provoca la rotación del rotor.
* **Control de Velocidad:** La velocidad es proporcional a la tensión media aplicada mediante modulación por ancho de pulso (PWM).
* **Control de Par:** El par electromecánico es directamente proporcional a la corriente eléctrica consumida por el motor ($\tau = K_t \cdot I$).

### 2.2 Reducción Mecánica de Velocidad (Spur Gearbox)
La caja de engranajes cilíndrica utiliza trenes de ruedas dentadas montadas en ejes paralelos para modificar la relación velocidad/par entre el eje del motor y el eje de salida final.
* **Ecuaciones de Conversión Mecánica:**
  $$\omega_{salida} = \frac{\omega_{rotor}}{i}$$
  $$\tau_{salida} = \tau_{rotor} \cdot i \cdot \eta$$
  *(donde $i$ es la relación de reducción de la caja y $\eta$ es la eficiencia de transferencia mecánica).*

### 2.3 Encoder Incremental de Cuadratura (Efecto Hall)
El módulo de lectura consta de un disco magnético multipolar fijo al eje del rotor y dos sensores de Efecto Hall integrados en la placa posterior colocados con un desfase espacial de $90^\circ$ eléctricos.

* **Generación de Onda:** Al girar el disco magnético, los cambios de flujo activan y desactivan los transistores del sensor de Hall, generando dos señales cuadradas digitales (Canal A y Canal B).
* **Determinación de Dirección:**
  * **Sentido Horario (CW):** El flanco de subida del **Canal A** precede al flanco de subida del **Canal B**.
  * **Sentido Antihorario (CCW):** El flanco de subida del **Canal B** precede al flanco de subida del **Canal A**.

---

## 3. Especificaciones Técnicas

### 3.1 Parámetros Eléctricos y Motrices (A 12V DC)

| Parámetro | Valor Típico | Unidad |
| :--- | :--- | :--- |
| **Voltaje Nominal Operativo** | 12.0 | V DC |
| **Rango de Tensión Permitido** | 6.0 – 15.0 | V DC |
| **Corriente en Vacío (No Load Current)** | $\le 0.15$ | A |
| **Corriente Típica Bajo Carga** | $0.8 – 1.4$ | A |
| **Corriente Máxima de Bloqueo (Stall Current)** | 3.2 | A |
| **Potencia Mecánica de Salida** | 10 – 15 | W |

### 3.2 Especificaciones del Encoder de Efecto Hall

| Parámetro | Valor | Unidad |
| :--- | :--- | :--- |
| **Tensión de Alimentación Lógica ($V_{cc}$)** | 3.3 – 5.0 | V DC |
| **Nivel Lógico de Salida** | TTL ($0V$ a $V_{cc}$) | - |
| **Pulsos por Revolución del Motor (PPR)** | 11 | PPR (Canal único) |
| **Cuentas por Revolución del Motor (CPR)** | 44 | CPR (En decodificación 4x) |
| **Frecuencia de Respuesta Máxima** | 100 | kHz |

*Nota: Para obtener el número total de pulsos por vuelta completa en el eje de salida final, se aplica la fórmula:*
$$\text{Pulsos Salida (PPR)} = 11 \times i$$
$$\text{Cuentas Salida (CPR)} = 44 \times i$$

---

## 4. Descripción del Conector y Pinout (6 Pines)

| Pin N° | Etiqueta | Función | Tipo de Señal / Conexión |
| :---: | :--- | :--- | :--- |
| **1** | M+ / Motor + | Alimentación (+) del Motor DC | Entrada de potencia (PWM / Tensión continua) |
| **2** | M- / Motor - | Alimentación (-) del Motor DC | Entrada de potencia (PWM / Tensión continua) |
| **3** | Hall GND | Tierra Lógica del Sensor | Tierra de referencia (0V) |
| **4** | Hall VCC | Alimentación Lógica Sensor | Entrada lógica regulada (3.3V – 5.0V DC) |
| **5** | Hall Out A | Salida Canal A del Encoder | Salida Digital TTL (Cuadratura A) |
| **6** | Hall Out B | Salida Canal B del Encoder | Salida Digital TTL (Cuadratura B) |

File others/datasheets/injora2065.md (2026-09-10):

# Ficha Técnica / Datasheet – Servomotor Digital INJORA INJ2065 (11g / 7kg.cm)

## 1. Descripción General
El **INJORA INJ2065** es un servomotor digital de tamaño micro diseñado para aplicaciones de alta densidad de potencia donde se requieren tiempos de respuesta mínimos, alto par de retención y alta resistencia al estrés mecánico. Incorpora un motor de tecnología *coreless*, caja de engranajes de aleación metálica y disipador térmico de aluminio integrado en la carcasa central.

---

## 2. Principio de Funcionamiento y Dinámica Electromecánica

### 2.1 Motor Coreless (Sin Núcleo de Hierro)
A diferencia de los motores DC tradicionales donde las bobinas están devanadas sobre un núcleo de hierro laminado, el motor *coreless* posee un devanado autosoportado cilíndrico de cobre que gira alrededor de un imán permanente central de alta intensidad.
* **Efecto Físico:** Elimina el momento de inercia asignado por la masa del hierro (*rotor cogging*). Esto se traduce en aceleraciones ultrarrápidas, respuesta dinámica instantánea y menor resistencia inductiva al cambio de sentido de giro.

### 2.2 Microcontrolador de Control Digital Integrado
El circuito de control lee la señal de entrada PWM proveniente del dispositivo anfitrión y procesa la diferencia angular a través de un microcontrolador interno a alta frecuencia (frecuencias de actualización internas >300 Hz). 
* **Banda Muerta (Deadband):** Al reducir la banda muerta a un nivel de 2 µs, el controlador reacciona ante variaciones de posición imperceptibles, aplicando pequeños pulsos de corriente para corregir y mantener la posición fijada.

### 2.3 Bucle Cerrado de Posición (Closed-Loop)
Un potenciómetro de alta precisión acoplado al eje de salida convierte el ángulo actual en un nivel de voltaje analógico. El controlador compara este valor en tiempo real con la posición solicitada mediante la señal PWM, ajustando dinámicamente la corriente aplicada por el puente H interno hacia el motor *coreless*.

---

## 3. Especificaciones Eléctricas y Mecánicas

### 3.1 Rendimiento Operativo

| Parámetro | Condición a 6.0V | Condición a 7.4V | Unidad |
| :--- | :--- | :--- | :--- |
| **Par de Bloqueo (Stall Torque)** | 6.0 (0.58) | 7.0 (0.68) | kg/cm (N.m) |
| **Velocidad Operativa (sin carga)** | 0.09 | 0.07 | sec / 60° |
| **Corriente en Vacío (No load)** | 50 | 60 | mA |
| **Corriente de Bloqueo (Stall Current)**| 1200 | 1500 | mA |
| **Banda Muerta (Deadband Width)** | 2 | 2 | µs |

### 3.2 Especificaciones Mecánicas y Constructivas

| Parámetro | Valor / Características |
| :--- | :--- |
| **Dimensiones Exteriores** | 23.0 mm x 12.5 mm x 26.5 mm |
| **Peso Total** | 11.0 gramos |
| **Material de Piñonería** | Acero Inoxidable / Aleación de Cobre |
| **Material de la Carcasa** | Polímero de alta resistencia con sección media de Aluminio CNC |
| **Sistema de Rodamientos** | Doble rodamiento de bolas (*Dual Ball Bearings*) |
| **Eje de Salida (Spline)** | 25T (Micro estrías) |

---

## 4. Señal de Control PWM y Protocolo

El servomotor se gobierna mediante la modulación del ancho de pulso de una señal cuadrada estándar.

* **Frecuencia de Cuadro:** 50 Hz a 330 Hz (Soporta tasas elevadas por ser de arquitectura digital).
* **Rango de Ancho de Pulso:** 500 µs a 2500 µs.
  * **500 µs:** Posición límite angular $0^\circ$.
  * **1500 µs:** Posición neutra / central $90^\circ$.
  * **2500 µs:** Posición límite angular $180^\circ$.

---

## 5. Mapeo de Conexión Eléctrica

| Color del Cable | Asignación | Descripción de Función |
| :---: | :--- | :--- |
| **Marrón / Negro** | GND | Tierra lógica y de potencia de referencia. |
| **Rojo** | VCC | Entrada de potencia (6.0V a 7.4V DC). |
| **Naranja / Blanco**| Signal | Entrada de la señal de control PWM. |

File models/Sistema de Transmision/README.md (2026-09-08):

### Sistema de Transmisión y Tracción Trasera

El tren motriz del robot integra un sistema de transmisión por engranajes diferenciales interconectados directamente mediante sus ejes de transmisión a las ruedas posteriores. Esta configuración optimiza la transferencia de par y asegura una tracción eficiente sin pérdida de potencia en línea recta ni resistencia residual durante los giros.

---

### Cinemática y Mecanismos de Transmisión

* **Piñón y Corona Doble Helicoidal (Herringbone):**  
  La potencia rotacional generada por el motor de tracción se transmite hacia la caja del diferencial mediante un par de engranajes con dentado doble helicoidal. Este perfil en "V" elimina por completo el empuje axial que sufren los engranajes helicoidales convencionales, ofreciendo un acoplamiento suave, un nivel de ruido mecánico mínimo y una distribución uniforme de la fuerza sobre la corona.

* **Núcleo del Diferencial (Satélites y Planetarios):**  
  Internamente, el núcleo del diferencial aloja un arreglo dinámico de engranajes satélite y planetarios. Los satélites giran libremente sobre su eje dentro de la caja de transmisión para permitir que los engranajes planetarios, acoplados a los palieres izquierdo y derecho, giren a velocidades independientes cuando el robot describe una curva.

* **Dinámica de Curvatura:**  
  Gracias a la compensación diferencial de velocidades, la rueda exterior en una curva puede girar más rápido que la rueda interior sin derrapar ni forzar la estructura. Este comportamiento mecánico es fundamental para ejecutar virajes fluidos y estables durante ángulos de cruce extremos, previniendo la pérdida de adherencia en el tren trasero.

  <p align="center">
    Esquema Superior del Sistema de Transmisión en CAD<br>
  </p>

---

## Ensamble Físico del Tren Motriz

El ensamble mecánico muestra la integración real de la caja del diferencial, la corona helicoidal exterior y los soportes de rodamientos fijados sobre la base del chasis:

<p align="center">
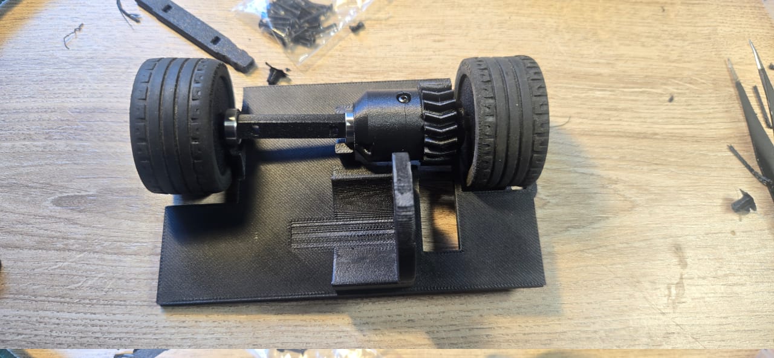
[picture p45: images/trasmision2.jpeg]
Ensamble Físico del Sistema de Transmisión Trasera
  <br>
</p>

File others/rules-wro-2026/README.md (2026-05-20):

# WRO 2026 Futuros Ingenieros - Reglas Oficiales

Este directorio contiene el reglamento técnico y de competencia oficial para la temporada 2026. Es el marco legal obligatorio que define los retos en pista, los criterios de puntuación y las restricciones de hardware que los equipos de la competencia debe cumplir rigurosamente.

## Archivo Incluido

**[`ESPANOL-WRO-2026-Future-Engineers-Self-Driving-Cars-General-Rules-Final.pdf`](https://github.com/yosoycrix/Valrepo-WRO-2026/blob/main/others/rules-wro-2026/ESPANOL-WRO-2026-Future-Engineers-Self-Driving-Cars-General-Rules-Final.pdf)**: Documento oficial de la WRO con las normas generales, especificaciones milimétricas del circuito, regulaciones de materiales y directrices de inspección técnica.

---

### 1. Reto Abierto (Open Challenge)
* **Objetivo:** El vehículo debe completar con éxito **3 vueltas consecutivas** al circuito en el menor tiempo posible de manera totalmente autónoma.
* **Dificultad:** El sentido de la marcha (horario o antihorario) se determina al azar antes de comenzar la ronda. Además, el tamaño del cuadro central puede modificarse entre intentos y evaluar la capacidad de adaptación del robot.
* **Meta:** Detenerse tras finalizar las 3 vueltas.

### 2. Reto Cerrado (Closed Challenge)
* **Gestión de Tráfico:** Se introducen pilares o bloques de tráfico de colores en la pista que el vehículo debe identificar y evadir en tiempo real utilizando sus sistemas de visión o sensores:
* **Bloques Rojos:** Deben ser evadidos obligatoriamente por el lado **derecho**.
* **Bloques Verdes:** Deben ser evadidos obligatoriamente por el lado **izquierdo**.
* **Estacionamiento Autónomo (Parqueo):** Tras completar las vueltas correspondientes, el vehículo debe detectar de manera autónoma una zona con bloques magenta (ubicada en uno de los cuadrantes de la pista) y realizar una maniobra de aparcamiento paralela completa y estática dentro de los límites señalados.

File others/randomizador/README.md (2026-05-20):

# WRO Futuros Ingenieros 2026 - Randomizador Oficial Del Team Valgrind

Este es el randomizador oficial programado y utilizado por el **Team Valgrind** para poder simular y entrenar de una manera muchisimo mas efectiva los desafíos de la categoría **Future Engineers** (Futuros Ingenieros) de la **World Robot Olympiad 2026 (WRO)**. 

Este Randomizador permite llegar a generar de una manera visual la pista de una manera completamente aleatoria, asi tal cual la posición de los muros perimetrales, la ubicación de los bloques de tráfico (rojos y verdes) y las zonas de estacionamiento conforme a los reglamentos de la competencia.

🌐 **Link hacia el Randomizador:** [https://yosoycrix.github.io/wro-futuros-ingenieros-randomizador-team-valgrind/](https://yosoycrix.github.io/wro-futuros-ingenieros-randomizador-team-valgrind/)

---

## 🛠️ Características Principales

* **Selector de Modo de Ronda:** Alterna fácilmente entre el Desafío Abierto y el Desafío Cerrado.
* **Visualización Dinámica:** Renderizado en tiempo real de la posición del robot, dirección de marcha, bloques y muros de la sección central.
* **Cronómetro Integrado:** Permite medir el tiempo exacto de cada lanzamiento en minutos, segundos y milisegundos para llevar un control de velocidad.
* **Historial de Lanzamientos:** Un registro interactivo que guarda cada pista generada con un identificador único, marca de tiempo y detalles específicos.
* **Sistema de Filtros avanzados:** Filtra el historial por tipo de ronda o por cuadrante específico para analizar escenarios particulares.

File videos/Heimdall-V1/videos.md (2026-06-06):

### Videos de Pruebas en Pista

> [!TIP]
> ### Fase 1: Open Challenge
> **Estado:** 🟢 Simulación Completada (12 Giros / 3 Vueltas)  
> 
> <a href="https://www.youtube.com/watch?v=o4KUQaZj4Cw" target="_blank">
>   Miniatura Open Challenge
> </a>  
> 
> 

---

> [!TIP]
> ### Fase 2: Obstacle Challenge
> **Estado:** 🟡 Pruebas de Desarrollo (Evitación de Bloques)  
> 
> <a href="https://www.youtube.com/watch?v=xPg1Bdj31Bs" target="_blank">
>   Miniatura Obstacle Challenge
> </a>  
> 
>

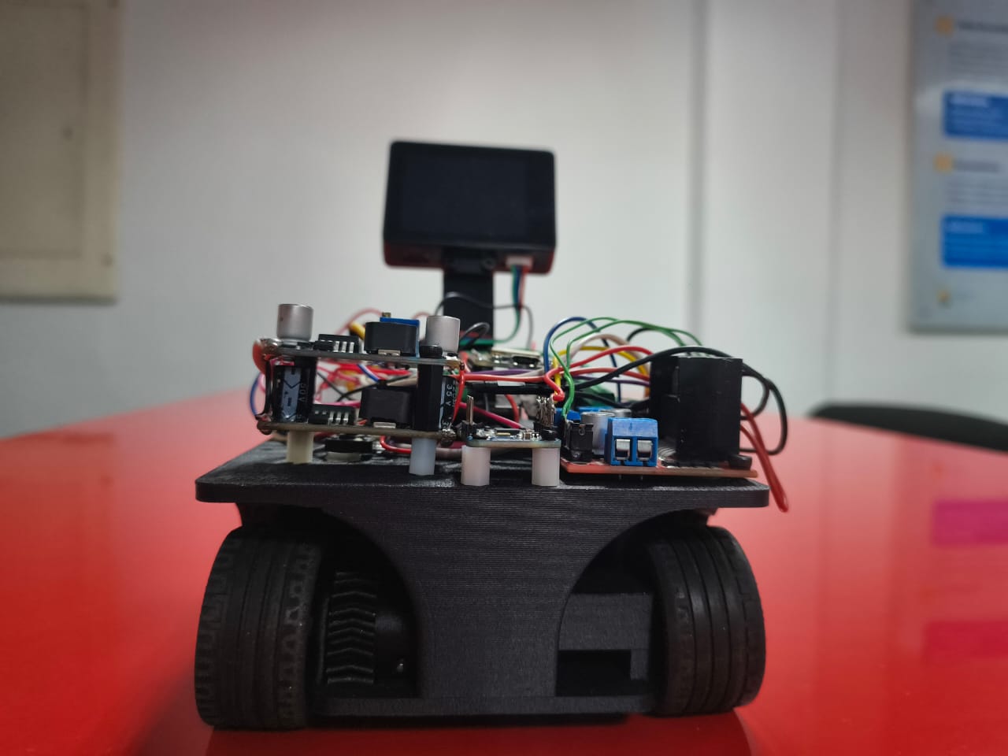
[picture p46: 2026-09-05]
v-photos/Heimdall-V3/posterior.jpeg

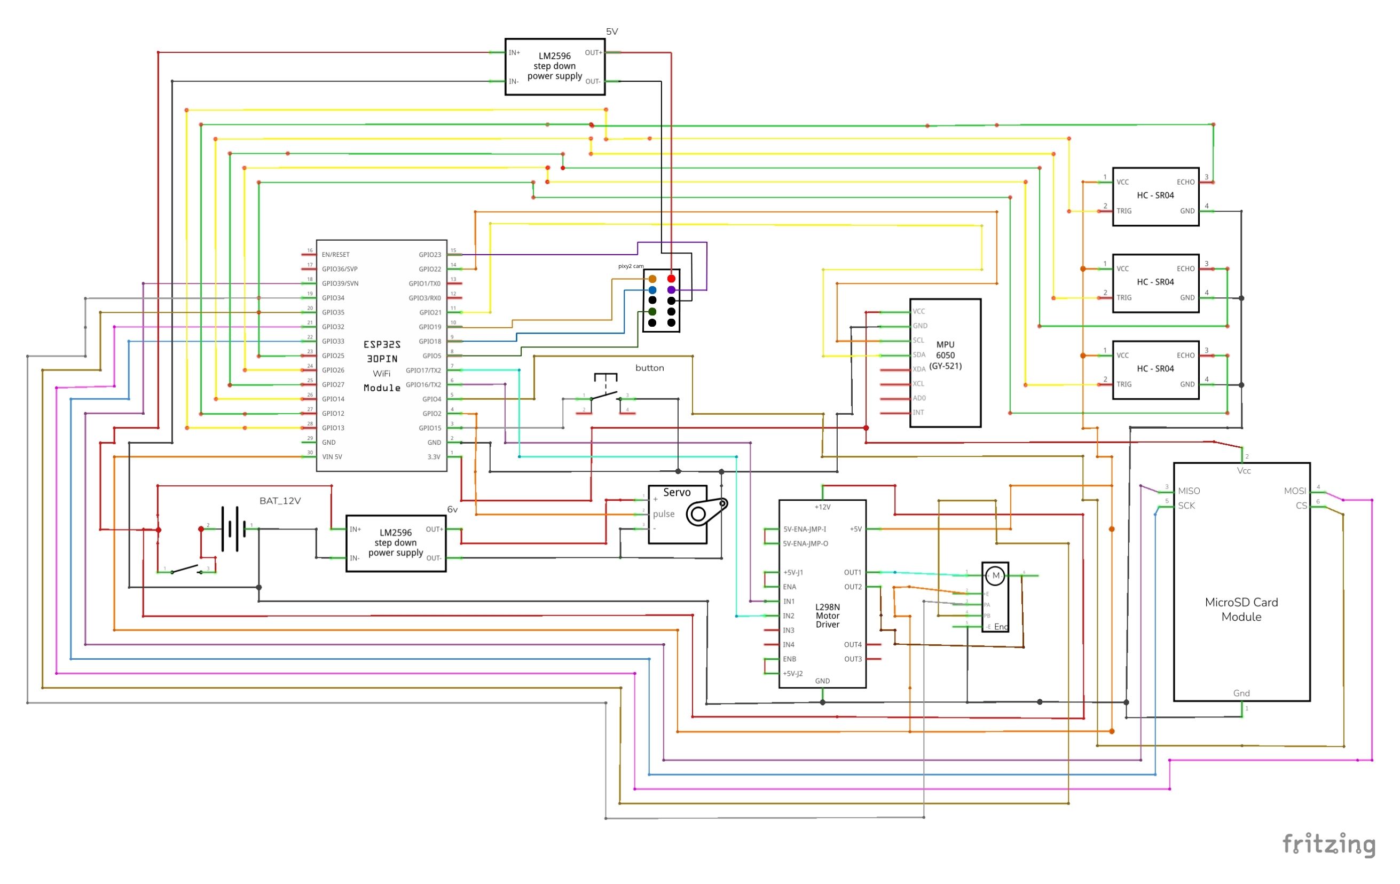
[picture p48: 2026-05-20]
schemes/electronics/Heimdall-V1/heimdall_diagrama.jpg

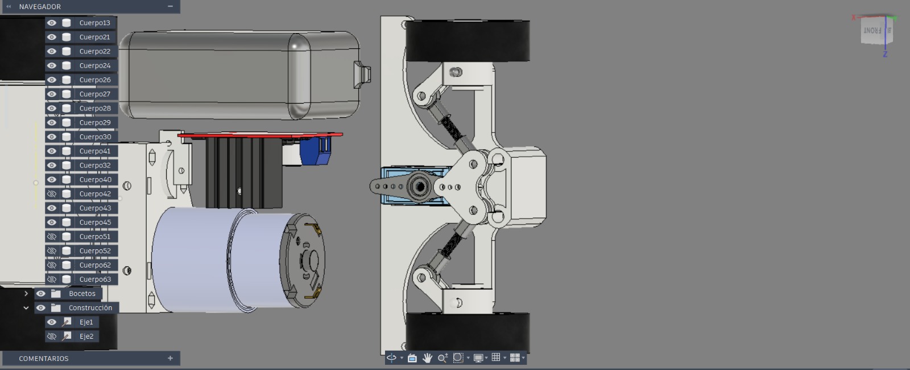
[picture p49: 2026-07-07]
images/delantera.jpeg

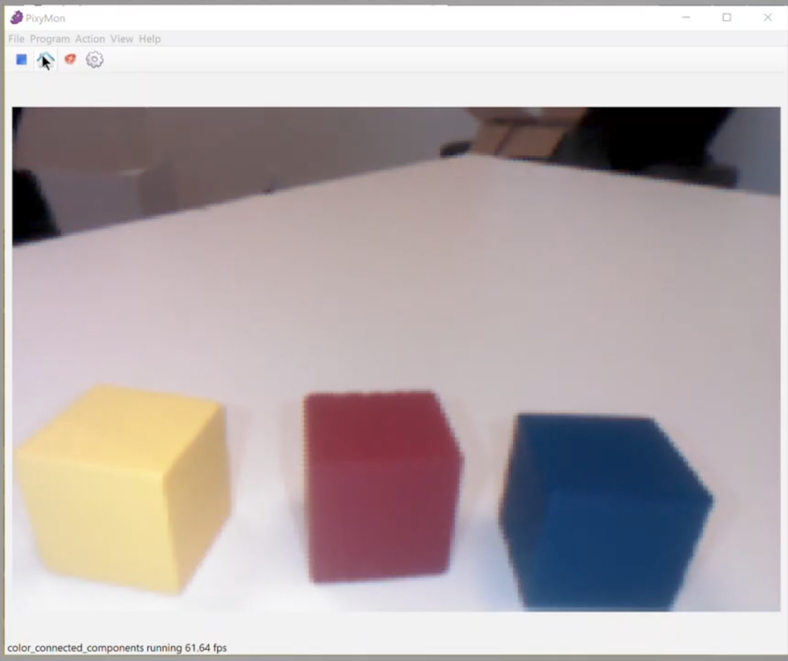
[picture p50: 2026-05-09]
images/deteccionpixy.jpg

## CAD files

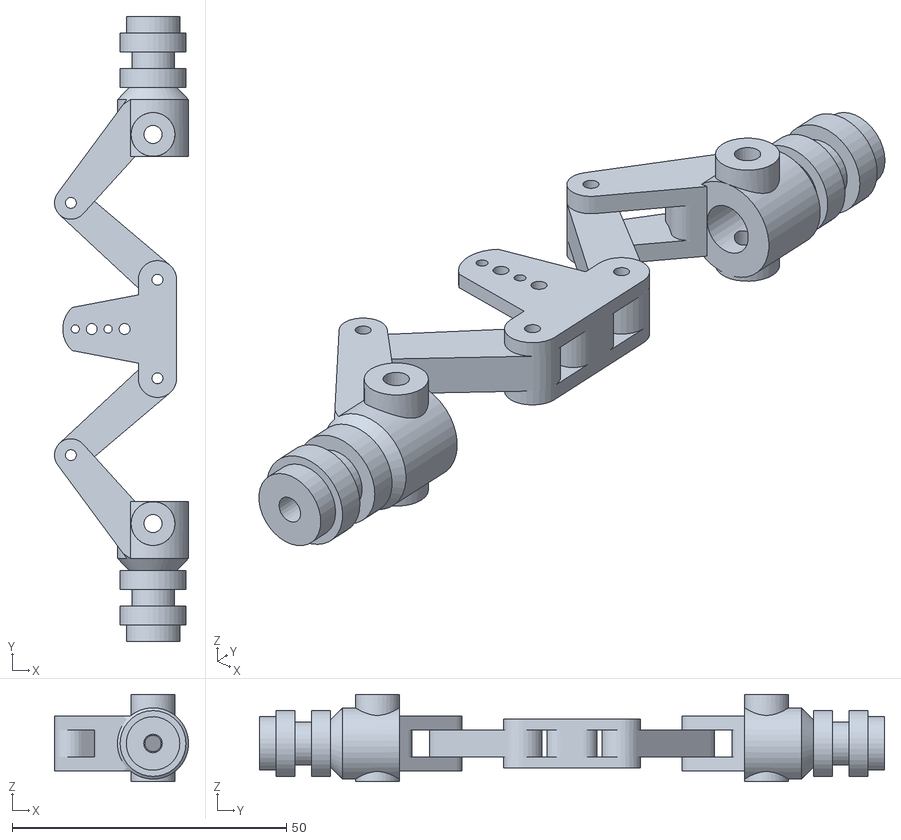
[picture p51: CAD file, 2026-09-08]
models/Sistema de Direccion/steering knuckle complete.stl
24.5 x 114.0 x 16.0

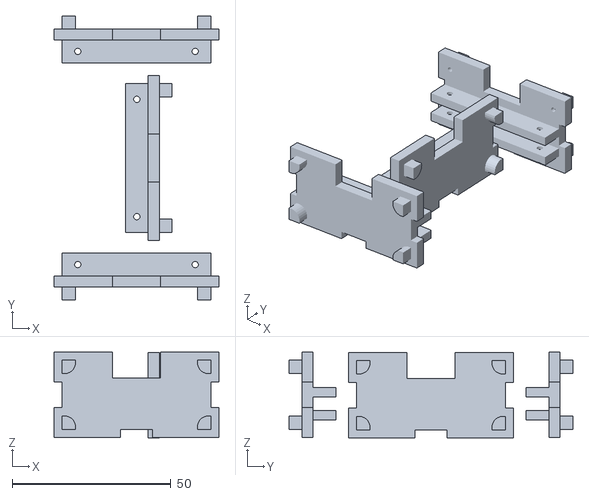
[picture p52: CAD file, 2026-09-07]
models/Bases y Acoples de Sensores y Camara/acople trasero de sensor.stl
52.0 x 89.4 x 27.1

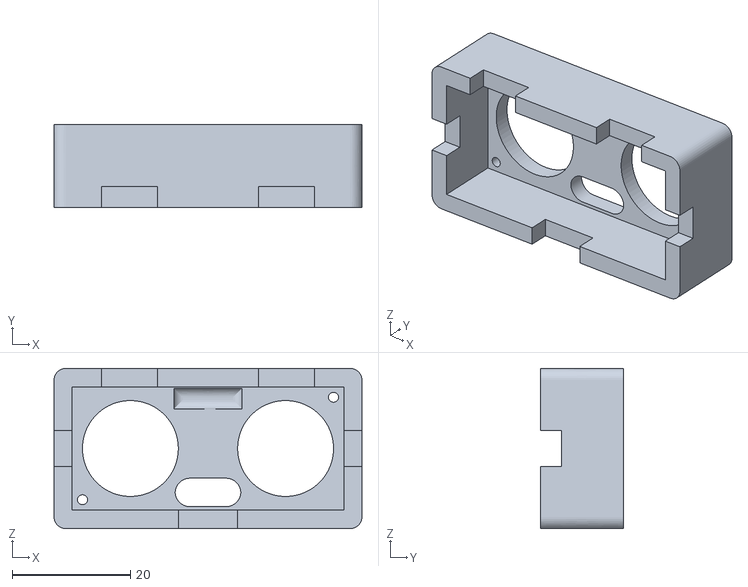
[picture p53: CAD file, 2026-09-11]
models/Heimdall desings 2025/Bases y Acoples de Sensores y Cámara/base de acople de ultrasonicos .stl
52.0 x 14.0 x 27.1

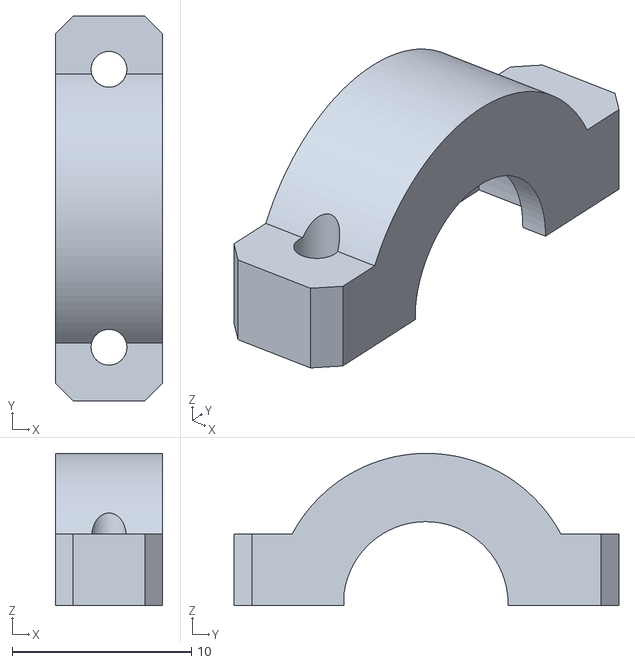
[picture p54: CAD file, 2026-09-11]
models/Heimdall desings 2025/Cajas de Diferencial y Chasis Principal/prisionero de rolinera de transmisión del motor al eje.stl
6.00 x 21.5 x 8.50

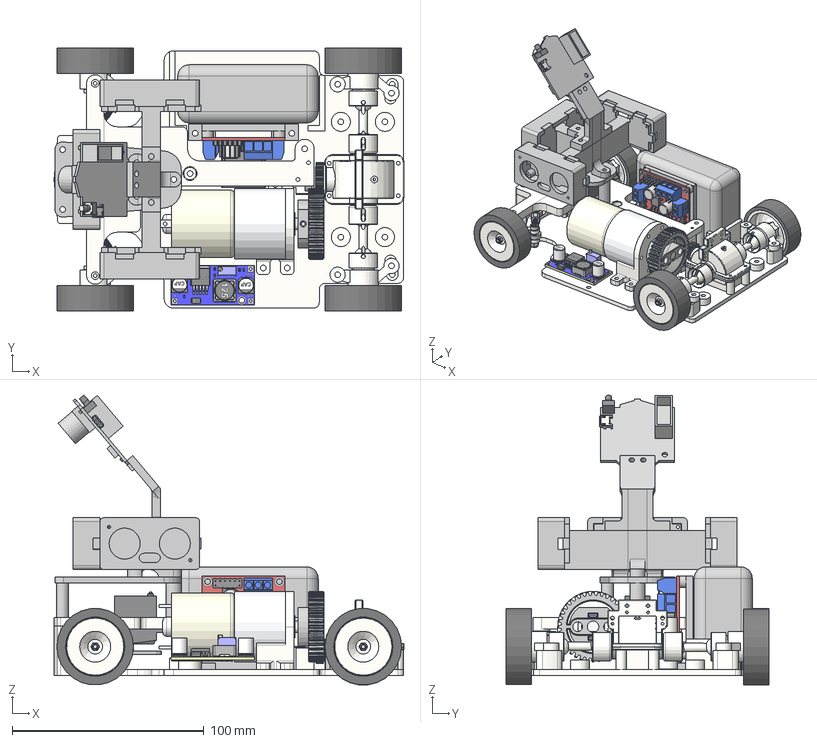
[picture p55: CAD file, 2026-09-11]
models/Heimdall desings 2025/Heimdall-Final-Version/heimdall definitive.step
182.8 x 137.4 x 151.3 mm
caja de diferencial superior
pivote reforzadio v1
rueda v1
M2 x 20 Screw head
M2
copa de diferencial v1
pivote reforzadio v1 (1)
rueda v1 (1)
M2 x 20 Screw head_1
M2_1
copa de diferencial v1 (1)
rueda x 2
rolinera 7x11x3 x 3
rolinera 12x8x3.5
6542 Black Technic Gear 16 Tooth with Clutch
acople de enranaje de lego de 36 dientes
Sin título v2
oalier reforzado v1 x 2
Componente2
Componente1
battery 12v
L298N Motor Driver
MG995_Gear2
pivote hexagonal v1
Pivote trasero v2
rolinera 12x8x3.5 v1 (4)
rolinera 12x8x3.5 v1 (5)
Sin título_Componente3 v1
M2 x 20 Screw head_2
M2_2
rueda v1 (2)
pivote hexagonal v1 (1)
Pivote trasero v2 (1)
rolinera 12x8x3.5 v1 (7)
rolinera 12x8x3.5 v1 (8)
Sin título_Componente3 v1 (1)
M2 x 20 Screw head_3
M2_3
rueda v1 (3)
rod end m3 mini x 4
Board^HW-411
RES_3296W^HW-411
TO-263-5^HW-411
CAP_SMD_AL_08.0x10.0^HW-411 x 2
RES_SMD_0603^HW-411 x 2
CAP_SMD_0603_H0.50^HW-411 x 2
001^CDRH125_HW-411
002^CDRH125_HW-411
005^CDRH125_HW-411 x 2
003^CDRH125_HW-411
Diode_DO214AC(SMA)^HW-411
LED_0603_Green^HW-411
m3-16mm x 2
M3x16 x 4
M3 Nyloc Nut x 4
CMUcam5 Pixy
ultrasonic case pt2 x 3
ultrasonic case pt1 v1
Sin título (~recovered) (~recovered)_Componente71 v1
Sin título (~recovered) (~recovered)_Componente71 v1 (1)

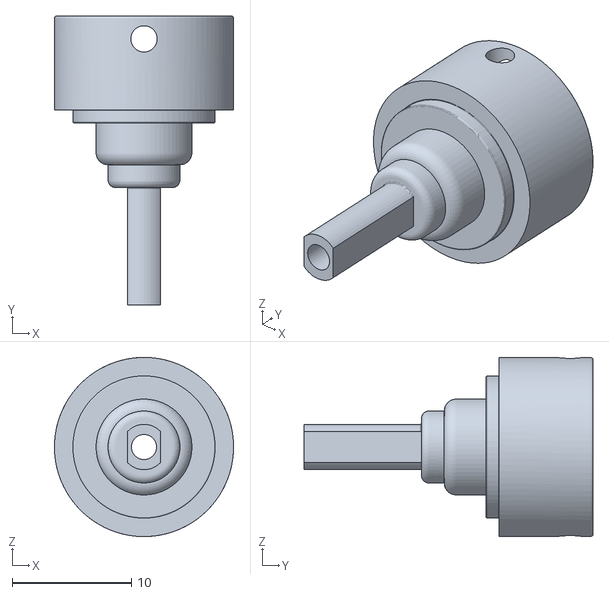
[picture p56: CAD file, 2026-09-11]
models/Heimdall desings 2025/Sistema de Movimiento Libre y Tracción Delantera/Junta delantera.stl
15.0 x 24.2 x 15.0

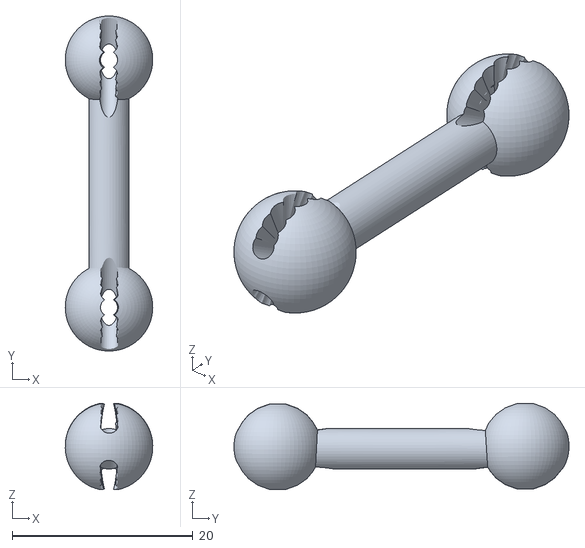
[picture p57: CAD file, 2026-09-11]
models/Heimdall desings 2025/Sistema de Transmisión Motriz Trasero/Palier de transmisión trasera (1).stl
9.69 x 37.1 x 9.57

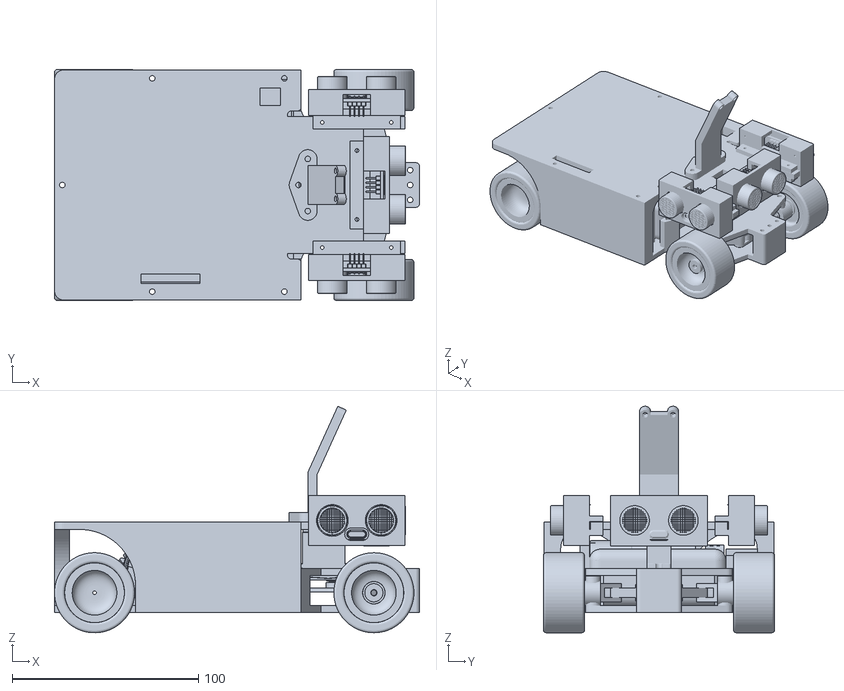
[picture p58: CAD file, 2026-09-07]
models/Heimdall Version Final/heimdall final.stl
196.0 x 124.0 x 121.7

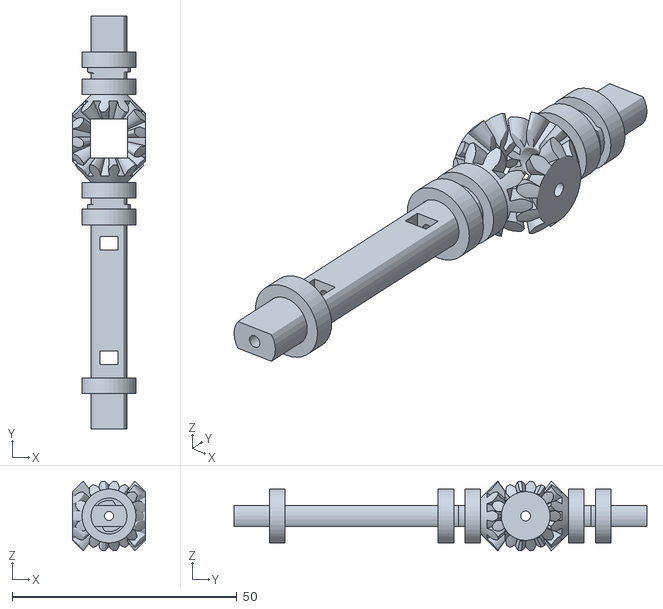
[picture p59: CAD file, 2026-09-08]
models/Sistema de Transmision/diferencial con los brazos y las rolineras.stl
16.2 x 91.9 x 15.5

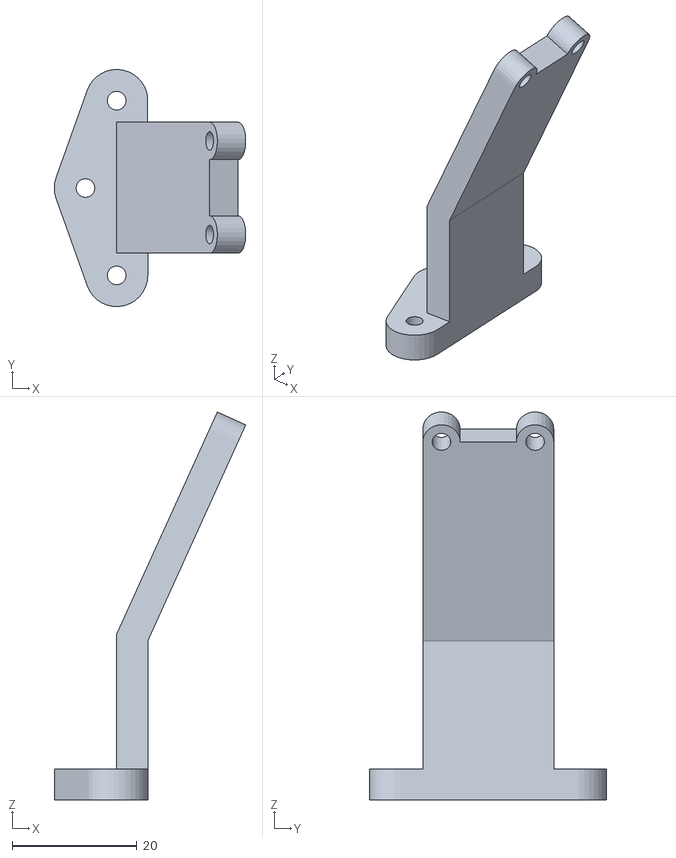
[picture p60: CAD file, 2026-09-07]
models/Bases y Acoples de Sensores y Camara/soporte camara.stl
30.7 x 38.0 x 62.2

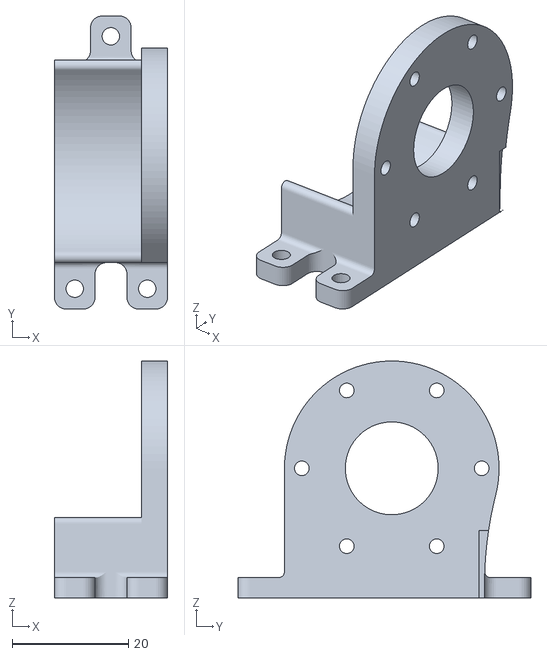
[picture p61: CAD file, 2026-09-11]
models/Heimdall desings 2025/Bases y Acoples de Sensores y Cámara/base de motor.stl
19.5 x 50.5 x 40.8

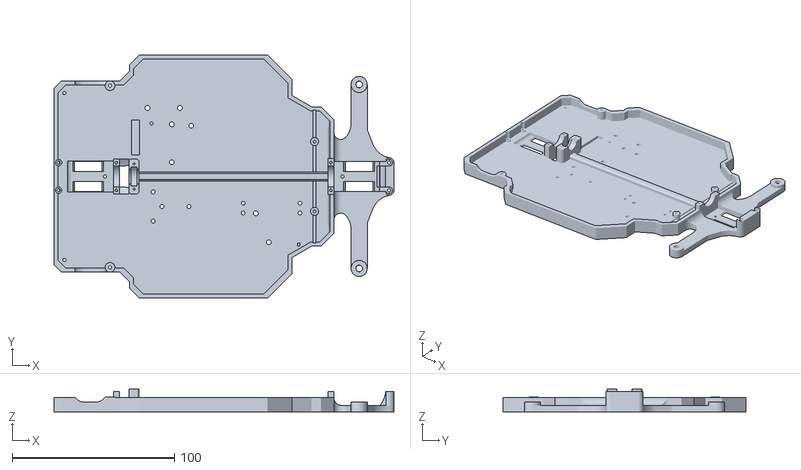
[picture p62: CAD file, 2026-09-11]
models/Heimdall desings 2025/Cajas de Diferencial y Chasis Principal/chasis principal.stl
209.6 x 150.0 x 14.0

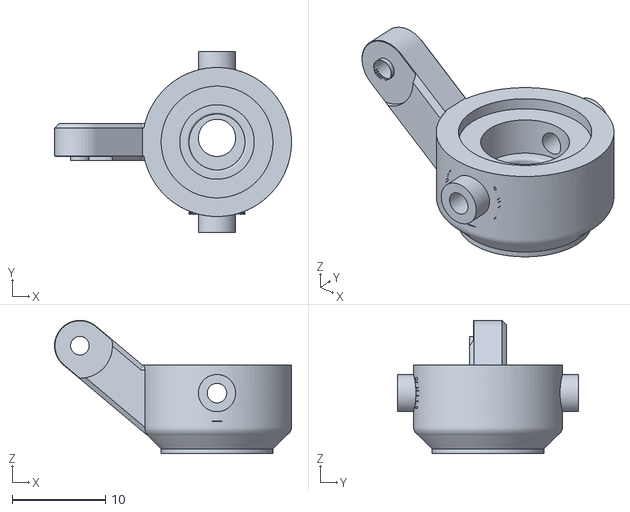
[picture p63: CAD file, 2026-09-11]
models/Heimdall desings 2025/Sistema de Movimiento Libre y Tracción Delantera/Pivote frontal.stl
25.5 x 19.4 x 14.3

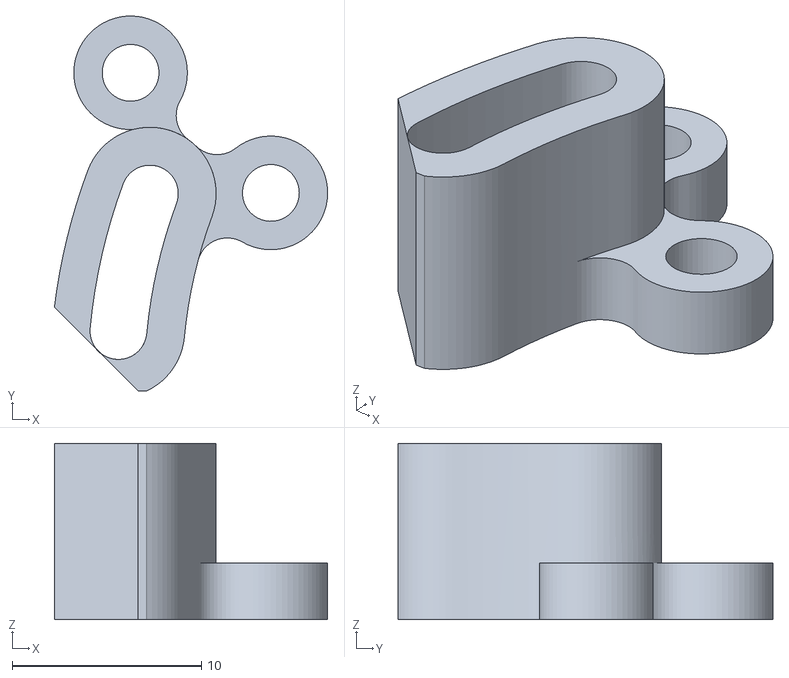
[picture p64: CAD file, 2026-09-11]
models/Heimdall desings 2025/Sistema de Transmisión Motriz Trasero/Alineador de transmisión trasera.stl
14.4 x 19.8 x 9.31

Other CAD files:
models/Sistema de Direccion/steering knuckle.stl
models/Sistema de Transmision/motor con engranaje.stl
models/Bases y Acoples de Sensores y Camara/acople delantero de sensores.stl
models/Heimdall desings 2025/Bases y Acoples de Sensores y Cámara/bracket de servo.stl
models/Heimdall desings 2025/Bases y Acoples de Sensores y Cámara/base de pixy.stl
models/Heimdall desings 2025/Bases y Acoples de Sensores y Cámara/base de ultrasonicos y pixy principal.stl
models/Heimdall desings 2025/Cajas de Diferencial y Chasis Principal/caja de diferencial inferior .stl
models/Heimdall desings 2025/Cajas de Diferencial y Chasis Principal/caja de diferencial superior.stl
models/Heimdall desings 2025/Sistema de Movimiento Libre y Tracción Delantera/Varilla de refuerzo de tren delantero.stl
models/Heimdall desings 2025/Sistema de Movimiento Libre y Tracción Delantera/caja de diferencial inferior .stl
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

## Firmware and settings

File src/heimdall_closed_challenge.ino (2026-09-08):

#include <Wire.h>
#include <NewPing.h>
#include <ESP32Servo.h>
#include <DFRobot_HuskylensV2.h>
#include <Adafruit_Sensor.h>
#include <Adafruit_BNO055.h>
#include <utility/imumaths.h>

// ----- VELOCIDADES -----
#define VELOCIDAD_NORMAL   210
#define VELOCIDAD_REVERSA   160
#define VELOCIDAD_RETROCESO_EVASIVO  50   // Velocidad para retroceso por obstáculo frontal

// ----- ÁNGULOS DEL SERVO -----
#define ANGULO_CENTRO       97
#define ANGULO_IZQUIERDA    54
#define ANGULO_DERECHA      140
#define ANGULO_ESQUIVA_IZQ  54
#define ANGULO_ESQUIVA_DER  140

// ----- TICKS DE ESQUIVA (VERDE) -----
#define TICKS_VERDE_PRIMER     510
#define TICKS_VERDE_SEGUNDO    610
#define TICKS_VERDE_GIRO_CONTRARIO   600
#define TICKS_VERDE_GIRO_VUELTA      600
#define TICKS_VERDE_RETROCESO_VERIF  290

// ----- TICKS DE ESQUIVA (ROJO) -----
#define TICKS_ROJO_PRIMER      440
#define TICKS_ROJO_SEGUNDO     530
#define TICKS_ROJO_GIRO_CONTRARIO   400
#define TICKS_ROJO_GIRO_VUELTA      490
#define TICKS_ROJO_RETROCESO_VERIF  230

// ----- TICKS POST-ESQUIVA COMUNES -----
#define TICKS_AVANCE_POST_ESQUIVA  0

// ----- TICKS PARA RETROCESO EVASIVO (obstáculo frontal) -----
#define TICKS_RETROCESO_EVASIVO 830

// ----- DISTANCIA FRONTAL PARA ACTIVAR RETROCESO EVASIVO (cm) -----
#define DISTANCIA_FRONTAL_UMBRAL  30

// ----- PID -----
const float KP = 1.8, KI = 0.1, KD = 0.25;
const int LIMITE_CORRECCION = 30, DEAD_BAND = 2;

// ----- HUSKYLENS -----
const int ID_ROJO = 1;
const int ID_VERDE = 2;
const int MITAD_PANTALLA = 320;
const int UMBRAL_CENTRO = 40;
const int UMBRAL_ALTURA = 230;

// ----- DISTANCIAS LATERALES -----
const int DISTANCIA_LATERAL_GIRO = 120;   // cm para considerar espacio libre

#define IN1 18
#define IN2 19
#define PIN_SERVO 2
#define MOTOR_PWM_CHANNEL 6
#define MOTOR_PWM_PIN IN1

#define ENCODER_PIN_A  34
#define ENCODER_PIN_B  35
#define RX_PIN 16
#define TX_PIN 17
#define PIN_BOTON 15

#define TRIG_FRONTAL   13
#define ECHO_FRONTAL   12
#define TRIG_IZQUIERDO  14
#define ECHO_IZQUIERDO  27
#define TRIG_DERECHO    26
#define ECHO_DERECHO    25
#define MAX_DISTANCIA   300

NewPing USFRONT(TRIG_FRONTAL, ECHO_FRONTAL, MAX_DISTANCIA);
NewPing USLEFT(TRIG_IZQUIERDO, ECHO_IZQUIERDO, MAX_DISTANCIA);
NewPing USRIGHT(TRIG_DERECHO, ECHO_DERECHO, MAX_DISTANCIA);
Servo myservo;
Adafruit_BNO055 bno = Adafruit_BNO055(55, 0x28, &Wire);
HuskylensV2 huskylens;

// BNO055
float anguloRelativo = 0, anguloReferencia = 0;
bool bnoListo = false;
unsigned long lastTimeBNO = 0;

// Encoder
volatile long encoderTicks = 0;
long ticksAlInicio = 0;

// HuskyLens
bool sensorConectado = false;
unsigned long lastHuskyRead = 0;
const unsigned long READ_INTERVAL = 50;

// Ultrasonidos
int distanciaIzquierda = 0, distanciaDerecha = 0;

// Estado del robot
bool bloqueDetectado = false;
int ID_detectado = 0;
int alturaBloque = 0;
int centroX = 0;
int posicionBloque = 0;   // -1: izquierda, 0: centro, 1: derecha

// PID
float errorAcumulado = 0, errorAnterior = 0;
unsigned long tiempoAnteriorPID = 0;

// Máquina de estados
enum Estado {
  BUSCANDO,
  ESQUIVANDO,
  AJUSTE_POST_ESQUIVA,
  RETROCESO_EVASIVO,
  DETENIDO_PERMANENTE
};
Estado estado = BUSCANDO;
int faseEsquiva = 0;
int ticksPrimer, ticksSegundo;
int ticksGiroContrario, ticksGiroVuelta, ticksRetrocesoVerif;
int direccionPrimer;      // 1 = derecha, -1 = izquierda
int direccionContraria;   // Lado contrario al de la esquiva
unsigned long tiempoInicioFase = 0;

bool programaIniciado = false;

bool iniciarBNO055() {
  Wire.begin(21, 22);
  Wire.setClock(400000);
  delay(2000);
  for (int i = 0; i < 10; i++) {
    if (bno.begin()) {
      bno.setExtCrystalUse(true);
      bno.setMode(OPERATION_MODE_COMPASS);
      sensors_event_t event;
      bno.getEvent(&event);
      float ang = event.orientation.x;
      if (ang > 180) ang -= 360;
      anguloRelativo = -ang;
      lastTimeBNO = micros();
      return true;
    }
    delay(500);
  }
  return false;
}

float getAnguloRelativo() {
  if (!bnoListo) return 0;
  imu::Vector<3> gyro = bno.getVector(Adafruit_BNO055::VECTOR_GYROSCOPE);
  sensors_event_t event;
  bno.getEvent(&event);
  float ang = event.orientation.x;
  if (ang > 180) ang -= 360;
  unsigned long ahora = micros();
  float dt = (ahora - lastTimeBNO) / 1000000.0;
  lastTimeBNO = ahora;
  if (dt > 0 && dt < 0.1) {
    anguloRelativo = 0.98 * (anguloRelativo + gyro.z() * dt) + 0.02 * (-ang);
    if (anguloRelativo > 180) anguloRelativo -= 360;
    if (anguloRelativo < -180) anguloRelativo += 360;
  }
  return anguloRelativo;
}

void IRAM_ATTR encoderISR() { encoderTicks++; }
void iniciarEncoder() {
  pinMode(ENCODER_PIN_A, INPUT_PULLUP);
  pinMode(ENCODER_PIN_B, INPUT_PULLUP);
  attachInterrupt(digitalPinToInterrupt(ENCODER_PIN_A), encoderISR, RISING);
  encoderTicks = 0;
}
void resetearTicks() { encoderTicks = 0; }
void guardarTicksInicio() { ticksAlInicio = encoderTicks; }
long obtenerTicksRecorridos() { return abs(encoderTicks - ticksAlInicio); }
bool alcanzoTicks(int objetivo) { return obtenerTicksRecorridos() >= objetivo; }

void avanzarMotor() {
  digitalWrite(IN1, HIGH);
  digitalWrite(IN2, LOW);
  ledcWrite(MOTOR_PWM_CHANNEL, VELOCIDAD_NORMAL);
}

// Retroceso normal para esquivas (usa VELOCIDAD_REVERSA)
void retroceder() {
  digitalWrite(IN1, LOW);
  digitalWrite(IN2, HIGH);
  ledcWrite(MOTOR_PWM_CHANNEL, VELOCIDAD_REVERSA);
}

// Retroceso específico para obstáculo frontal (usa VELOCIDAD_RETROCESO_EVASIVO)
void retrocederEvasivo() {
  digitalWrite(IN1, LOW);
  digitalWrite(IN2, HIGH);
  ledcWrite(MOTOR_PWM_CHANNEL, VELOCIDAD_RETROCESO_EVASIVO);
}

void detenerMotor() {
  digitalWrite(IN1, LOW);
  digitalWrite(IN2, LOW);
  ledcWrite(MOTOR_PWM_CHANNEL, 0);
}

void aplicarPID() {
  if (!bnoListo) { myservo.write(ANGULO_CENTRO); avanzarMotor(); return; }
  float anguloActual = getAnguloRelativo();
  float error = anguloReferencia - anguloActual;
  if (error > 180) error -= 360;
  if (error < -180) error += 360;
  if (abs(error) < DEAD_BAND) {
    errorAcumulado = 0; errorAnterior = 0;
    myservo.write(ANGULO_CENTRO);
    avanzarMotor();
    return;
  }
  unsigned long ahora = millis();
  float dt = (ahora - tiempoAnteriorPID) / 1000.0;
  if (dt <= 0) dt = 0.01;
  float P = KP * error;
  errorAcumulado += error * dt;
  errorAcumulado = constrain(errorAcumulado, -50, 50);
  float I = KI * errorAcumulado;
  float D = KD * (error - errorAnterior) / dt;
  float correccion = constrain(P + I + D, -LIMITE_CORRECCION, LIMITE_CORRECCION);
  int anguloServo = constrain(ANGULO_CENTRO + (int)correccion, ANGULO_IZQUIERDA, ANGULO_DERECHA);
  myservo.write(anguloServo);
  avanzarMotor();
  errorAnterior = error;
  tiempoAnteriorPID = ahora;
}

void resetearPID() {
  errorAcumulado = 0;
  errorAnterior = 0;
  tiempoAnteriorPID = millis();
}

void leerHusky() {
  if (millis() - lastHuskyRead < READ_INTERVAL) return;
  lastHuskyRead = millis();

  if (!sensorConectado) {
    sensorConectado = huskylens.begin(Serial2);
    if (sensorConectado) {
      huskylens.switchAlgorithm(ALGORITHM_COLOR_RECOGNITION);
      Serial.println("HuskyLens reconectado");
    }
    return;
  }

  int resultCount = huskylens.getResult(ALGORITHM_COLOR_RECOGNITION);
  bloqueDetectado = false;
  ID_detectado = 0;
  alturaBloque = 0;
  centroX = 0;
  posicionBloque = 0;

  if (resultCount > 0) {
    while (huskylens.available(ALGORITHM_COLOR_RECOGNITION)) {
      Result* result = huskylens.popCachedResult(ALGORITHM_COLOR_RECOGNITION);
      if (result == NULL) continue;

      int id = result->ID;
      int x = result->xCenter;
      int h = result->height;

      if (id == 0) continue;

      if ((id == ID_ROJO || id == ID_VERDE) && h > UMBRAL_ALTURA) {
        int pos = 0;
        if (x < MITAD_PANTALLA - UMBRAL_CENTRO) pos = -1;
        else if (x > MITAD_PANTALLA + UMBRAL_CENTRO) pos = 1;
        else pos = 0;

        bool posicionCorrecta = (id == ID_VERDE && pos == 1) || (id == ID_ROJO && pos == -1);
        if (posicionCorrecta) {
          Serial.printf("Bloque ID=%d | centroX=%3d | altura=%3d | POSICION: %s (CORRECTA, no se esquiva)\n",
                        id, x, h, (pos == -1) ? "IZQUIERDA" : (pos == 1) ? "DERECHA" : "CENTRO");
          continue;
        }

        if (!bloqueDetectado) {
          bloqueDetectado = true;
          ID_detectado = id;
          centroX = x;
          alturaBloque = h;
          posicionBloque = pos;

          String posStr = (posicionBloque == -1) ? "IZQUIERDA" :
                          (posicionBloque == 1) ? "DERECHA" : "CENTRO";
          Serial.printf("Bloque ID=%d | centroX=%3d | altura=%3d | POSICION: %s (INCORRECTA, esquiva)\n",
                        id, centroX, alturaBloque, posStr.c_str());
          Serial.println("   Bloque valido. Activando esquiva...");
        }
      }
    }
  } else if (resultCount < 0) {
    sensorConectado = false;
  }
}

void decidirDireccionEsquiva() {
  if (posicionBloque == -1) {
    direccionPrimer = 1;
    direccionContraria = -1;
    Serial.println("   Bloque a IZQUIERDA -> esquivando a DERECHA");
  } else if (posicionBloque == 1) {
    direccionPrimer = -1;
    direccionContraria = 1;
    Serial.println("   Bloque a DERECHA -> esquivando a IZQUIERDA");
  } else {
    if (ID_detectado == ID_VERDE) {
      direccionPrimer = 1;
      direccionContraria = -1;
      Serial.println("   Bloque en CENTRO (VERDE) -> esquivando a DERECHA (por defecto)");
    } else {
      direccionPrimer = -1;
      direccionContraria = 1;
      Serial.println("   Bloque en CENTRO (ROJO) -> esquivando a IZQUIERDA (por defecto)");
    }
  }

  if (ID_detectado == ID_VERDE) {
    ticksPrimer = TICKS_VERDE_PRIMER;
    ticksSegundo = TICKS_VERDE_SEGUNDO;
    ticksGiroContrario = TICKS_VERDE_GIRO_CONTRARIO;
    ticksGiroVuelta = TICKS_VERDE_GIRO_VUELTA;
    ticksRetrocesoVerif = TICKS_VERDE_RETROCESO_VERIF;
    Serial.println("   (VERDE) Ticks post-esquiva asignados");
  } else { // ROJO
    ticksPrimer = TICKS_ROJO_PRIMER;
    ticksSegundo = TICKS_ROJO_SEGUNDO;
    ticksGiroContrario = TICKS_ROJO_GIRO_CONTRARIO;
    ticksGiroVuelta = TICKS_ROJO_GIRO_VUELTA;
    ticksRetrocesoVerif = TICKS_ROJO_RETROCESO_VERIF;
    Serial.println("   (ROJO) Ticks post-esquiva asignados");
  }
}

void leerSensores() {
  distanciaIzquierda = USLEFT.ping_cm();
  distanciaDerecha = USRIGHT.ping_cm();
  if (distanciaIzquierda == 0) distanciaIzquierda = MAX_DISTANCIA;
  if (distanciaDerecha == 0) distanciaDerecha = MAX_DISTANCIA;
}

// ================================================================
// ===== SETUP ====================================================
// ================================================================
void setup() {
  Serial.begin(115200);
  Serial.println("\n=== ROBOT - ESQUIVA DE BLOQUES + RETROCESO EVASIVO ===");
  Serial.printf("Velocidad avance: %d | Retroceso normal: %d | Retroceso evasivo: %d\n",
                VELOCIDAD_NORMAL, VELOCIDAD_REVERSA, VELOCIDAD_RETROCESO_EVASIVO);
  Serial.printf("Distancia frontal umbral: %d cm\n", DISTANCIA_FRONTAL_UMBRAL);

  pinMode(IN1, OUTPUT); pinMode(IN2, OUTPUT);
  pinMode(PIN_BOTON, INPUT_PULLUP);
  ledcSetup(MOTOR_PWM_CHANNEL, 5000, 8);
  ledcAttachPin(MOTOR_PWM_PIN, MOTOR_PWM_CHANNEL);
  myservo.attach(PIN_SERVO);
  myservo.write(ANGULO_CENTRO);
  detenerMotor();
  iniciarEncoder();

  bnoListo = iniciarBNO055();
  if (!bnoListo) { Serial.println("BNO055 no detectado"); while(1); }
  anguloReferencia = getAnguloRelativo();
  Serial.printf("Referencia inicial: %.1f\n", anguloReferencia);

  Serial2.begin(115200, SERIAL_8N1, RX_PIN, TX_PIN);
  sensorConectado = huskylens.begin(Serial2);
  if (sensorConectado) {
    huskylens.switchAlgorithm(ALGORITHM_COLOR_RECOGNITION);
    Serial.println("HuskyLens conectado - Modo Color Recognition");
  } else {
    Serial.println("HuskyLens no detectado");
  }

  tiempoAnteriorPID = millis();
  Serial.println("Presione el boton para iniciar...");
}

void loop() {
  if (!programaIniciado) {
    if (digitalRead(PIN_BOTON) == LOW) {
      programaIniciado = true;
      estado = BUSCANDO;
      faseEsquiva = 0;
      Serial.println("Iniciando!");
      delay(300);
    }
    return;
  }

  leerHusky();
  leerSensores();

  switch (estado) {

    case BUSCANDO: {
      aplicarPID();

      // 1. Prioridad: bloque en posición incorrecta y cerca
      if (bloqueDetectado) {
        Serial.printf("Esquivando bloque ID=%d\n", ID_detectado);
        decidirDireccionEsquiva();
        estado = ESQUIVANDO;
        faseEsquiva = 0;
        guardarTicksInicio();
        tiempoInicioFase = millis();
        if (direccionPrimer == 1) myservo.write(ANGULO_ESQUIVA_DER);
        else myservo.write(ANGULO_ESQUIVA_IZQ);
        break;
      }

      // 2. Obstáculo frontal + espacio lateral → retroceso evasivo
      int frontal = USFRONT.ping_cm();
      if (frontal == 0) frontal = MAX_DISTANCIA;

      if (frontal <= DISTANCIA_FRONTAL_UMBRAL) {
        bool izquierdaLibre = (distanciaIzquierda > DISTANCIA_LATERAL_GIRO);
        bool derechaLibre = (distanciaDerecha > DISTANCIA_LATERAL_GIRO);

        if (izquierdaLibre || derechaLibre) {
          int anguloGiro;
          if (derechaLibre) {
            anguloGiro = ANGULO_ESQUIVA_IZQ;   // girar a izquierda
            Serial.printf("Obstáculo frontal (%d cm) y espacio a DERECHA -> girando servo a IZQUIERDA y retrocediendo %d ticks (vel %d)\n",
                          frontal, TICKS_RETROCESO_EVASIVO, VELOCIDAD_RETROCESO_EVASIVO);
          } else {
            anguloGiro = ANGULO_ESQUIVA_DER;   // girar a derecha
            Serial.printf("Obstáculo frontal (%d cm) y espacio a IZQUIERDA -> girando servo a DERECHA y retrocediendo %d ticks (vel %d)\n",
                          frontal, TICKS_RETROCESO_EVASIVO, VELOCIDAD_RETROCESO_EVASIVO);
          }

          estado = RETROCESO_EVASIVO;
          faseEsquiva = 0;
          guardarTicksInicio();
          tiempoInicioFase = millis();
          myservo.write(anguloGiro);
          delay(50);
          retrocederEvasivo();   // Usa velocidad específica
          break;
        }
      }

      // Si no hay bloque ni obstáculo frontal, sigue avanzando (PID ya activo)
      break;
    }

    case RETROCESO_EVASIVO:
      if (alcanzoTicks(TICKS_RETROCESO_EVASIVO) || (millis() - tiempoInicioFase > 1500)) {
        detenerMotor();
        delay(50);
        myservo.write(ANGULO_CENTRO);
        // Reiniciar PID y actualizar referencia al ángulo actual
        resetearPID();
        anguloReferencia = getAnguloRelativo();
        estado = BUSCANDO;
        faseEsquiva = 0;
        Serial.println("Retroceso evasivo completado. Volviendo a BUSCANDO.\n");
        delay(200);
      }
      break;

    case ESQUIVANDO:
      // Fase 0: primer giro
      if (faseEsquiva == 0) {
        if (alcanzoTicks(ticksPrimer) || (millis() - tiempoInicioFase > 2000)) {
          Serial.printf("  Primer giro (%d ticks)\n", ticksPrimer);
          faseEsquiva = 1;
          guardarTicksInicio();
          tiempoInicioFase = millis();
          if (direccionPrimer == 1) myservo.write(ANGULO_ESQUIVA_IZQ);
          else myservo.write(ANGULO_ESQUIVA_DER);
        }
      }
      // Fase 1: segundo giro
      else if (faseEsquiva == 1) {
        if (alcanzoTicks(ticksSegundo) || (millis() - tiempoInicioFase > 2000)) {
          Serial.printf("  Segundo giro (%d ticks)\n", ticksSegundo);
          faseEsquiva = 2;
          myservo.write(ANGULO_CENTRO);
          detenerMotor();
          delay(100);
          guardarTicksInicio();
          tiempoInicioFase = millis();
          retroceder();   // Usa VELOCIDAD_REVERSA
          Serial.printf("  Retroceso de verificación (%d ticks)\n", ticksRetrocesoVerif);
        }
      }
      // Fase 2: retroceso de verificación
      else if (faseEsquiva == 2) {
        if (alcanzoTicks(ticksRetrocesoVerif) || (millis() - tiempoInicioFase > 1500)) {
          detenerMotor();
          delay(100);
          estado = AJUSTE_POST_ESQUIVA;
          faseEsquiva = 0;
          guardarTicksInicio();
          tiempoInicioFase = millis();
          myservo.write(ANGULO_CENTRO);
          avanzarMotor();
          Serial.printf("Iniciando avance recto de %d ticks (post-esquiva)\n", TICKS_AVANCE_POST_ESQUIVA);
        }
      }
      break;

    case AJUSTE_POST_ESQUIVA:
      // FASE 0: Avance recto (post-esquiva)
      if (faseEsquiva == 0) {
        if (alcanzoTicks(TICKS_AVANCE_POST_ESQUIVA) || (millis() - tiempoInicioFase > 1500)) {
          Serial.printf("  Avance recto completado (%d ticks)\n", TICKS_AVANCE_POST_ESQUIVA);
          faseEsquiva = 1;
          guardarTicksInicio();
          tiempoInicioFase = millis();
          if (direccionContraria == 1) myservo.write(ANGULO_ESQUIVA_DER);
          else myservo.write(ANGULO_ESQUIVA_IZQ);
          avanzarMotor();
          Serial.println("  Iniciando giro contrario (post-esquiva)");
        }
      }
      // FASE 1: Giro contrario
      else if (faseEsquiva == 1) {
        if (alcanzoTicks(ticksGiroContrario) || (millis() - tiempoInicioFase > 1500)) {
          Serial.printf("  Giro contrario completado (%d ticks)\n", ticksGiroContrario);
          faseEsquiva = 2;
          guardarTicksInicio();
          tiempoInicioFase = millis();
          if (direccionPrimer == 1) myservo.write(ANGULO_ESQUIVA_DER);
          else myservo.write(ANGULO_ESQUIVA_IZQ);
          avanzarMotor();
          Serial.println("  Iniciando giro de vuelta al centro");
        }
      }
      // FASE 2: Giro de vuelta
      else if (faseEsquiva == 2) {
        if (alcanzoTicks(ticksGiroVuelta) || (millis() - tiempoInicioFase > 1500)) {
          Serial.printf("  Giro de vuelta completado (%d ticks)\n", ticksGiroVuelta);
          myservo.write(ANGULO_CENTRO);
          detenerMotor();

          // Reiniciar PID y actualizar referencia al ángulo actual
          resetearPID();
          anguloReferencia = getAnguloRelativo();
          estado = BUSCANDO;
          faseEsquiva = 0;
          Serial.println("Post-esquiva completada. Continuando navegación.\n");
          delay(200);
        }
      }
      break;

    case DETENIDO_PERMANENTE:
      detenerMotor();
      break;
  }

  delay(5);
}

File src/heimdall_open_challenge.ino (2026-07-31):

#include <Wire.h>
#include <NewPing.h>
#include <ESP32Servo.h>

#include <Adafruit_Sensor.h>
#include <Adafruit_BNO055.h>
#include <utility/imumaths.h>

#define USTFRONT 13
#define USEFRONT 12
#define USTLEFT 14
#define USELEFT 27
#define USTRIGHT 26
#define USERIGHT 25

#define MAX_DISTANCE 357

#define IN2 19
#define IN1 18
#define PIN_SERVO 2
#define PIN_BOTON 15

NewPing USFRONT(USTFRONT, USEFRONT, MAX_DISTANCE);
NewPing USLEFT(USTLEFT, USELEFT, MAX_DISTANCE);
NewPing USRIGHT(USTRIGHT, USERIGHT, MAX_DISTANCE);

Servo myservo;

Adafruit_BNO055 bno = Adafruit_BNO055(55, 0x28, &Wire);

float anguloZ = 0;
float anguloFiltrado = 0;
float anguloMagnetometro = 0;
float anguloGiroscopio = 0;
unsigned long lastTimeBNO = 0;
bool bnoListo = false;

float anguloAcumulado = 0;
float anguloObjetivoRelativo = 0;
float anguloInicioGiroRelativo = 0;

const float ANGULO_GIRO_IZQUIERDA = 86.0;   // Grados que gira a la izquierda
const float ANGULO_GIRO_DERECHA = 71.3;     // Grados que gira a la derecha

const int DISTANCIA_OBSTACULO_FRONTAL = 40;
const int DISTANCIA_OBSTACULO_LATERAL = 120;
const unsigned long TIEMPO_ESPERA_GIRO = 700;
const int MAX_GIROS = 12;
const float AJUSTE_GIRO_RETROCESO = 0.2;
const int GRADOS_MAX_RETROCESO = 80;

const int COMPENSACION_CENTRO_IZQUIERDA = 0;
const int CENTRO_BASE = 95;
int centroServoActual = CENTRO_BASE;

const int ANGULO_SERVO_IZQ = 120;
const int ANGULO_SERVO_DER = 60;

bool programaIniciado = false;
bool finalizado = false;
bool girando = false;
bool enAvanceFinal = false;
bool giroIzquierda = false;
bool retrocediendo = false;
bool retrocesoRealizado = false;
bool recalculandoGiro = false;
bool obstaculoFrontalConfirmado = false;

unsigned long tiempoUltimoGiro = 0;
unsigned long tiempoInicioFinal = 0;
unsigned long tiempoInicioRetroceso = 0;
unsigned long tiempoInicioFrontal = 0;
int contadorGiros = 0;
int lecturasFrontales = 0;

float anguloObjetivo = 0;
float gyro = 0;
float anguloInicioGiro = 0;
float anguloOriginal = 0;
float anguloNecesario = 0;
float errorAcumulado = 0;

bool iniciarBNO055() {
  Serial.println("Inicializando BNO055...");
  
  Wire.begin(21, 22);
  Wire.setClock(400000);
  
  delay(2000);
  
  for (int intento = 0; intento < 10; intento++) {
    Serial.print("Intento ");
    Serial.print(intento + 1);
    Serial.print("/10... ");
    
    if (bno.begin()) {
      Serial.println("OK");
      bno.setExtCrystalUse(true);
      bno.setMode(OPERATION_MODE_COMPASS);
      
      uint8_t system, gyro, accel, mag;
      bno.getCalibration(&system, &gyro, &accel, &mag);
      Serial.print("Estado: S:");
      Serial.print(system);
      Serial.print(" G:");
      Serial.print(gyro);
      Serial.print(" A:");
      Serial.print(accel);
      Serial.print(" M:");
      Serial.println(mag);
      
      sensors_event_t event;
      bno.getEvent(&event);
      anguloMagnetometro = event.orientation.x;
      if (anguloMagnetometro > 180) anguloMagnetometro -= 360;
      
      anguloZ = -anguloMagnetometro;
      anguloFiltrado = anguloZ;
      anguloGiroscopio = anguloZ;
      lastTimeBNO = micros();
      
      anguloAcumulado = 0;
      
      return true;
    }
    
    Serial.println("FALLÓ");
    delay(500);
  }
  
  return false;
}

void actualizarBNO() {
  if (!bnoListo) return;
  
  imu::Vector<3> gyro = bno.getVector(Adafruit_BNO055::VECTOR_GYROSCOPE);
  
  sensors_event_t event;
  bno.getEvent(&event);
  anguloMagnetometro = event.orientation.x;
  if (anguloMagnetometro > 180) anguloMagnetometro -= 360;
  
  unsigned long ahora = micros();
  float dt = (ahora - lastTimeBNO) / 1000000.0;
  lastTimeBNO = ahora;
  
  if (dt > 0 && dt < 0.1) {
    anguloGiroscopio += gyro.z() * dt;
    
    anguloFiltrado = 0.95 * (anguloFiltrado + gyro.z() * dt) + 0.05 * (-anguloMagnetometro);
    if (anguloFiltrado > 180) anguloFiltrado -= 360;
    if (anguloFiltrado < -180) anguloFiltrado += 360;
    
    anguloZ = anguloFiltrado;
  }
}

float getGyro() {
  actualizarBNO();
  return anguloZ;
}

float getAnguloRelativo() {
  imu::Vector<3> gyro = bno.getVector(Adafruit_BNO055::VECTOR_GYROSCOPE);
  
  unsigned long ahora = micros();
  float dt = (ahora - lastTimeBNO) / 1000000.0;
  lastTimeBNO = ahora;
  
  if (dt > 0 && dt < 0.1) {
    anguloAcumulado += gyro.z() * dt;
  }
  
  return anguloAcumulado;
}

void resetearAnguloAcumulado() {
  anguloAcumulado = 0;
  Serial.println("Ángulo acumulado resetado a 0");
}

float normalizarError(float error) {
  if (error > 180) error -= 360;
  if (error < -180) error += 360;
  return error;
}

void motorAdelante() {
  digitalWrite(IN1, HIGH);
  digitalWrite(IN2, LOW);
}

void motorRetroceder() {
  digitalWrite(IN1, LOW);
  digitalWrite(IN2, HIGH);
}

void motorParar() {
  digitalWrite(IN1, LOW);
  digitalWrite(IN2, LOW);
}

void servoCentro() {
  if (girando || retrocediendo || enAvanceFinal) {
    myservo.write(CENTRO_BASE);
  } else {
    myservo.write(centroServoActual);
  }
}

void actualizarCentroServo(bool giroFueIzquierda) {
  if (giroFueIzquierda) {
    centroServoActual = CENTRO_BASE + COMPENSACION_CENTRO_IZQUIERDA;
    Serial.printf("Centro para RECTA ajustado a %d\n", centroServoActual);
  } else {
    centroServoActual = CENTRO_BASE;
    Serial.printf("Centro para RECTA restaurado a %d\n", centroServoActual);
  }
}

int leerUltrasonico(NewPing &sensor) {
  int d = sensor.ping_cm();
  if (d == 0) return -1;
  return d;
}

int correccionServo(float error) {
  float ae = abs(error);
  
  if (ae > 35) return 25;
  if (ae > 20) return 15;
  if (ae > 10) return 8;
  return 4;
}

void Adelante() {
  motorAdelante();
  servoCentro();
}

void Parar() {
  motorParar();
}

void iniciarGiroIzquierda() {
  float anguloActual = getAnguloRelativo();
  anguloInicioGiroRelativo = anguloActual;
  anguloOriginal = ANGULO_GIRO_IZQUIERDA;
  anguloObjetivoRelativo = anguloActual + ANGULO_GIRO_IZQUIERDA;
  
  giroIzquierda = true;
  girando = true;
  retrocediendo = false;
  retrocesoRealizado = false;
  recalculandoGiro = false;
  obstaculoFrontalConfirmado = false;
  lecturasFrontales = 0;
  
  myservo.write(ANGULO_SERVO_IZQ);
  motorAdelante();
  
  Serial.printf("Inicio giro IZQUIERDA: Actual: %.1f° | Objetivo: %.1f°\n", 
                anguloActual, anguloObjetivoRelativo);
}

void iniciarGiroDerecha() {
  float anguloActual = getAnguloRelativo();
  anguloInicioGiroRelativo = anguloActual;
  anguloOriginal = ANGULO_GIRO_DERECHA;
  anguloObjetivoRelativo = anguloActual - ANGULO_GIRO_DERECHA;
  
  giroIzquierda = false;
  girando = true;
  retrocediendo = false;
  retrocesoRealizado = false;
  recalculandoGiro = false;
  obstaculoFrontalConfirmado = false;
  lecturasFrontales = 0;
  
  myservo.write(ANGULO_SERVO_DER);
  motorAdelante();
  
  Serial.printf("Inicio giro DERECHA: Actual: %.1f° | Objetivo: %.1f°\n", 
                anguloActual, anguloObjetivoRelativo);
}
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

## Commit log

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2026-05-08 Update README with INJORA 7KG 2065 servo details
    Added detailed specifications and image for INJORA 7KG 2065 Digital Micro Servo 360°.
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2026-05-08 Update servo description for INJORA 2065 360°
    Removed outdated text and updated servo description.
2026-05-08 Revise INJORA 7KG 2065 servo section in README
    Updated the section for INJORA 7KG 2065 Digital Micro Servo 360° with improved formatting and specifications.
2026-05-08 Update reasons for choosing motor and reduction system
    Removed redundant text and fixed heading formatting.
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2026-05-08 Update README with battery specifications
    Added specifications table for Tenergy NiMH batteries.
2026-05-08 Update battery specifications in README
    Added detailed specifications for the battery including amperage, weight, dimensions, manufacturer, and customer ratings.
2026-05-08 Add specifications for LM2596 step-down regulator
    Added detailed specifications for the LM2596 step-down regulator, including input/output ranges, maximum current, efficiency, frequency, operating temperature, dimensions, and protections.
2026-05-09 Fix formatting issue in battery usage tips
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2026-05-09 Revise sensor sections in README
    Updated README to include Giroscopio (MPU6050) section and modified PixyCam entry.
2026-05-09 Fix gyroscope reference in README.md
2026-05-09 Fix gyroscope section title in README
    Updated the section title and link for the gyroscope.
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2026-05-09 Enhance README with ESP32 details and color detection
    Updated the README.md to include detailed information about the ESP32 microcontroller and its functionalities, along with enhancements to the color detection training section.
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2026-05-09 Update README with Pixy2 and SD module details
    Corrected formatting and added warnings and tips regarding the use of the Pixy2 camera and SD module. Enhanced clarity on the advantages of using SPI over I2C for communication.
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2026-05-09 Revise ESP32 to ESP32-WROOM-32 and enhance details
    Updated ESP32 section and specifications in README.
2026-05-09 Revise INJORA 7KG 2065 servo specifications in README
    Updated specifications and details for the INJORA 7KG 2065 Digital Micro Servo, including new tables and improved formatting.
2026-05-13 Enhance README with robot images and 3D printing info
    Added a table with images for various views of the robot and updated the 3D printing section.
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2026-05-16 Revise motor section in README for GA37-520
    Updated motor specifications and details for GA37-520.
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2026-05-16 Replace motor image and remove specifications
    Updated motor image and removed specifications section.
2026-05-16 Revise Step Down section with new table format
    Updated the Step Down section with a new table layout and improved styling. Added detailed specifications for the LM2596 regulator.
2026-05-16 Fix formatting and update servomotor section in README
2026-05-16 Fix section numbering for servomotor and motor
2026-05-16 Correct link for Servomotor in README
    Fixed link for Servomotor section in the README.
2026-05-16 Fix formatting of servomotor section in README
2026-05-16 Fix typo in servomotor section link
2026-05-16 Fix servomotor link in README
    Corrected link formatting for servomotor section.
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2026-05-16 Revise differential and axle descriptions in README
    Updated section on transmission differentials and axles, including changes to terminology and descriptions for clarity.
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2026-05-20 Update README by removing project structure section
    Removed project structure section from README and retained advanced filters description.
2026-05-31 Update README with vehicle challenge details
    Added objectives, restrictions, and random factors for the autonomous vehicle challenge. Included flowchart and code explanation for better understanding.
2026-05-31 Revise README for clarity on code structure and logic
    Updated the README to enhance the explanation of the code and its components, including the definition of pins and constants for the ESP32. Added details on the state machine algorithm and its intera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
2026-06-07 Add used printer details to README
    Added information about the used printer model to the README.
2026-06-07 Revise component list and printer information in README
    Updated the README to include links to various components and a note on the used printer.
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2026-07-12 Fix paragraph formatting for M2 and M3 section
    Corrected formatting of a paragraph regarding M2 and M3 screws.
2026-07-12 Enhance README with M2 and M3 screws details
    Added explanation for the use of M2 and M3 screws in robot mechanics.
2026-07-22 Revise sensor details for MPU6050 and BNO055
    Updated specifications and descriptions for MPU6050 and BNO055 sensors in the README. Added details on sensor fusion and calibration methods.
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2026-07-30 actualizar diseño de tabla de lista de los pines de la esp32
2026-07-30 corregir errores de diseñp de tabla de pines de la esp32
2026-07-30 correcion de nombres de la tabla de lista de pines de esp32
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2026-07-31 agregar nuevos videos a la carpeta videos y hacer carpea de videos de heimdall v1
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2026-09-02 Revise README for code updates and explanations
    Updated README to reflect changes in code structure and functionality, including sensor initialization and control logic.
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2026-09-05 Enhance Ackermann steering system section in README
    Updated image description and styling in the README.
2026-09-07 Enhance README with detailed robot functionality
    Updated README.md to include detailed explanations of the robot's flowchart, code structure, and control algorithms. Added sections on PID control, state machine, and sensor integration for enhanced 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
2026-09-07 agregar diseños 3d, actualiar el readme principal entre diversas cosas
    [acople delantero de sensores.stl, acople trasero de sensor.stl, soporte camara.stl]
2026-09-07 arreglar fotos dell readme de bases y acoples de camras y sensores
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2026-09-07 arreglar tamaño de fotos
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2026-09-07 agregar stl
    [donde se agarrra la palanca del servo.stl, los brazos q cruzan.stl]
2026-09-07 actuaalizar nombres de diseños 3d
    [boquilla del bracket del servo.stl, brazos de direccion.stl]
2026-09-08 modificar diseños
    [steering knuckle complete.stl, steering knuckle.stl]
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2026-09-11 agregar diseños 2025
    [Alineador de transmisión trasera.stl, Junta delantera.stl, Junta trasera.stl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]
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
